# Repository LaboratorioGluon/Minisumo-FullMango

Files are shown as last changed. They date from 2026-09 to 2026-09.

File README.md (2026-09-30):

# 🤖 Robot 🤖 Minisumo FullMango

Mi robot de competición para la OSHWDEM 2026, el minisumo :tangerine: **FullMango** :tangerine:  (Perdón, no había emoji de un mango).

Hecho 100% en directos de Twitch y Youtube, desde las pruebas de concepto, la electrónica con PCB y la programación del microcontrolador de ST.
-   Twitch: [www.twitch.tv/labgluon](https://www.twitch.tv/labgluon)
-   Youtube: [www.youtube.com/labgoratoriogluon](www.youtube.com/labgoratoriogluon)

<p align="center">
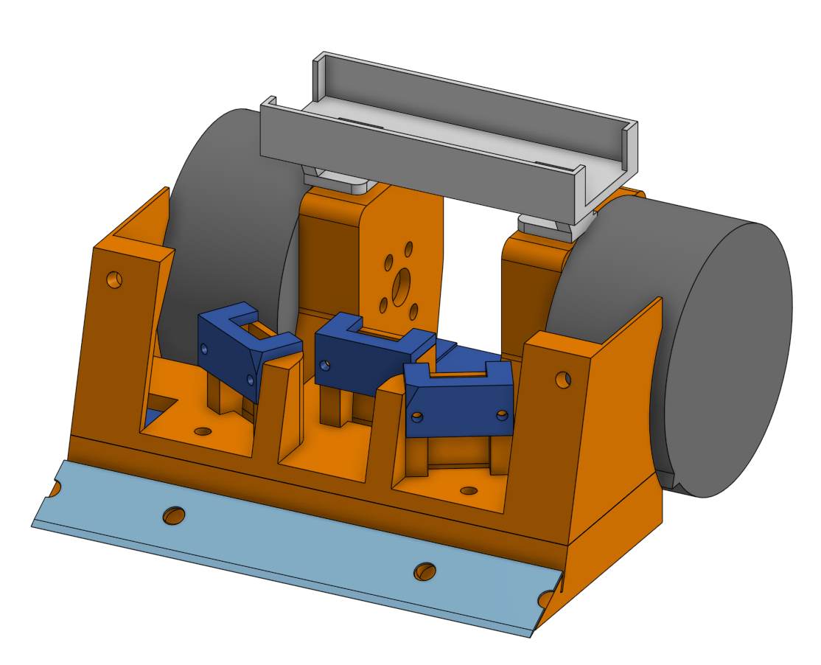
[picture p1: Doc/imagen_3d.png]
Imagen 3D

</p>

# :wrench: Componentes Principales :wrench:
- **PCB** : Diseño propio hecho en KiCAD, proyecto en carpeta `Schematics/MinisumoV2/`
- **Estructura:** Para añadir peso y consistencia esta basado en placas perforadas de acero cincado.
    - Diseño 3D alrededor de estas piezas hecho en OnShape (carpeta `3D').
- **Motores**: De maquina de tatuaje, coreless (Modelo M2610, Ref: [Aliexpress](https://es.aliexpress.com/item/4001010632280.html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))
- **Electrónica**:
    - *Procesador*: **STM32H523CCT6**
    - *Driver motores*: **MP6551**
    - *Sensor de línea*: **QRE1113** (Ref: [Aliexpress](https://s.click.aliexpress.com/e/_c4XDYlMh))
    - *Senor de enemigo*:  **GP2Y0E03** (Ref [Aliexpress](https://s.click.aliexpress.com/e/_c443dXyh))
    - *Alimentación* :
        - Batería 3S Tattu 550 mAh
        - Regulador switching: **TPS563201**
        - Regulador lineal: **AMS1117-3.3**

# :computer: Sobre el Software :computer:

El robot minisumo FullMango se basa en un control por máquina de estados. Siendo los 3 principales:
- **Wait RC5** (`start_state` en el código): Una vez que el Robot se ha inicializado correctamente espera a la señal del **mando RC5**
- **Seek** (`seek_state`): Es el patrón de búsqueda hasta encontrar al enemigo.
- **Attack** (`fight_state`): Cuando el robot ya ha encontrado al enemigo y va a por él.

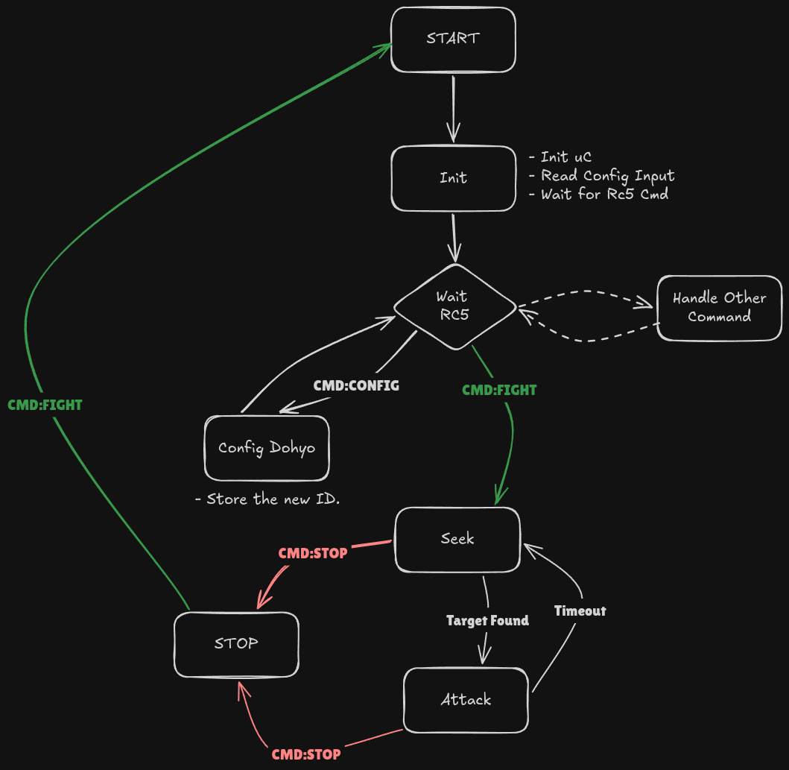
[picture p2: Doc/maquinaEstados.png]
Maquina de Estados de SW.


## Control de motores

Para el control de motores se ha implementado una doble rampa de cara a intentar resolver el problema de los caballitos: los motores son muy potentes y si pasamos al 80% de golpe, el **robot se da la vuelta**.

# Configuracion

| Pin | Function |
| --- | --- |
| Ninguno | FWD |
| 1 | RIGHT |
| 2 | LEFT |
| 3 | BACK |

# Otros enlaces

- [Pagina Web (Castellano)](https://www.laboratoriogluon.com/)
- [Webpage (English)](https://en.laboratoriogluon.com/)

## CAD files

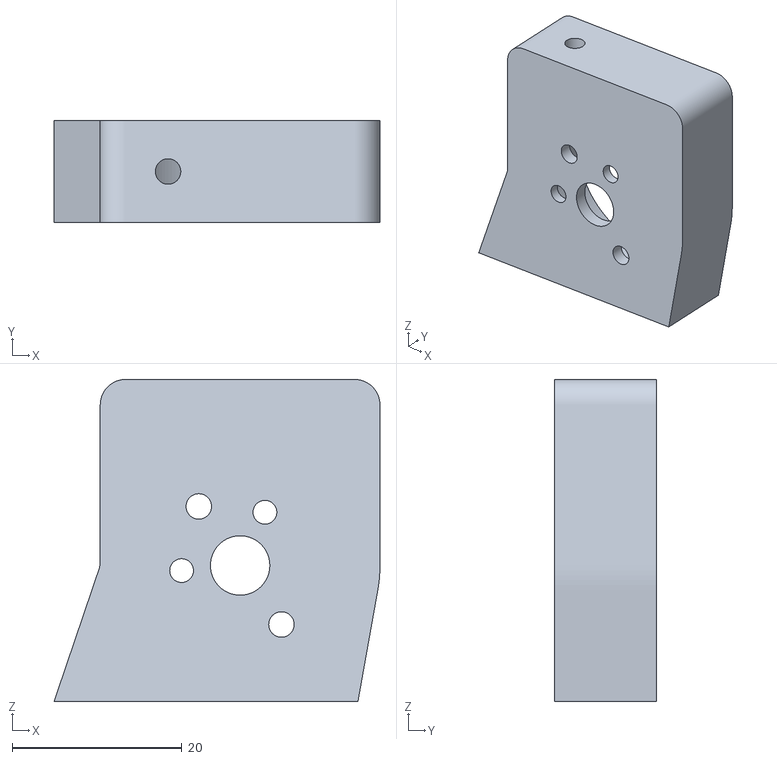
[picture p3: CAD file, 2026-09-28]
3D/FullMango-SoporteDrch.stl
38.5 x 12.0 x 38.0

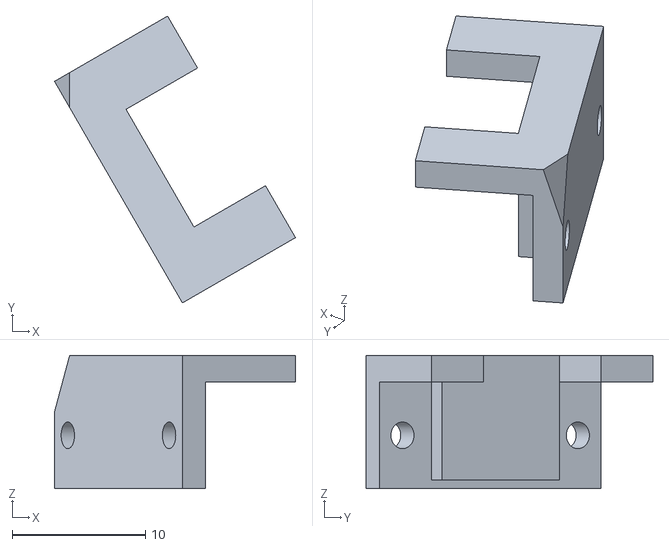
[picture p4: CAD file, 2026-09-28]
3D/FullMango-Part 16.stl
18.1 x 21.5 x 10.00

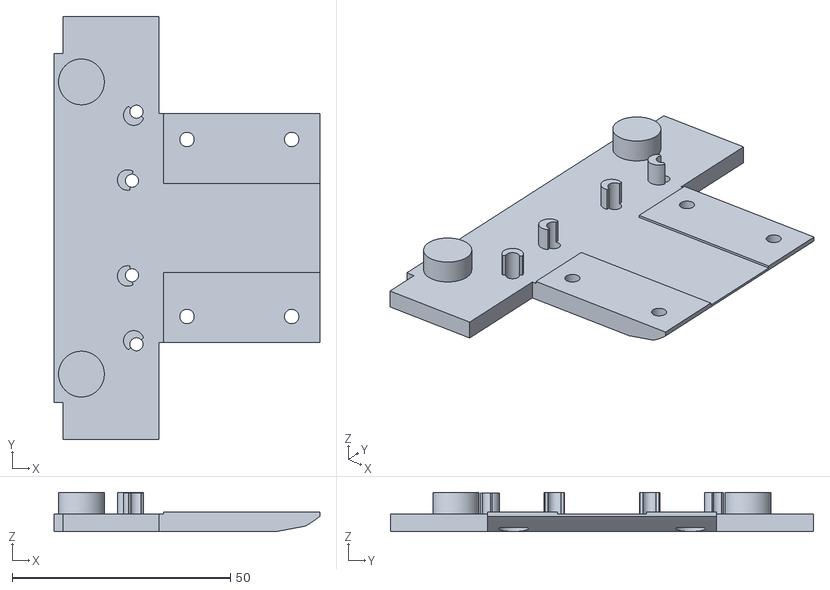
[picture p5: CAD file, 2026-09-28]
3D/FullMango-BaseTRas.stl
60.9 x 97.0 x 9.00

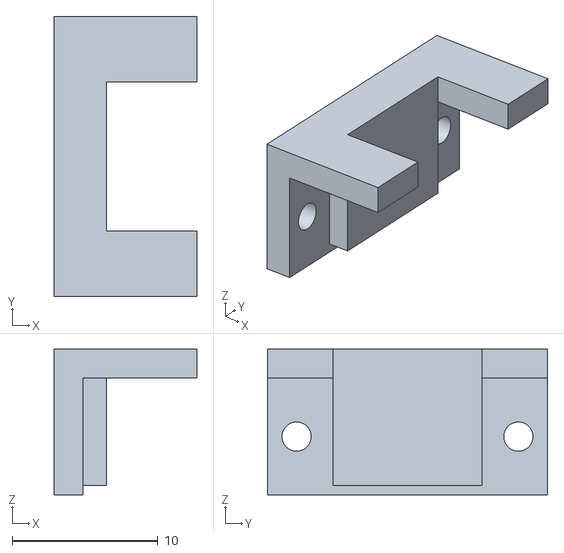
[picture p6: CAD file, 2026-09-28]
3D/FullMango-Part 14.stl
9.80 x 19.2 x 10.00

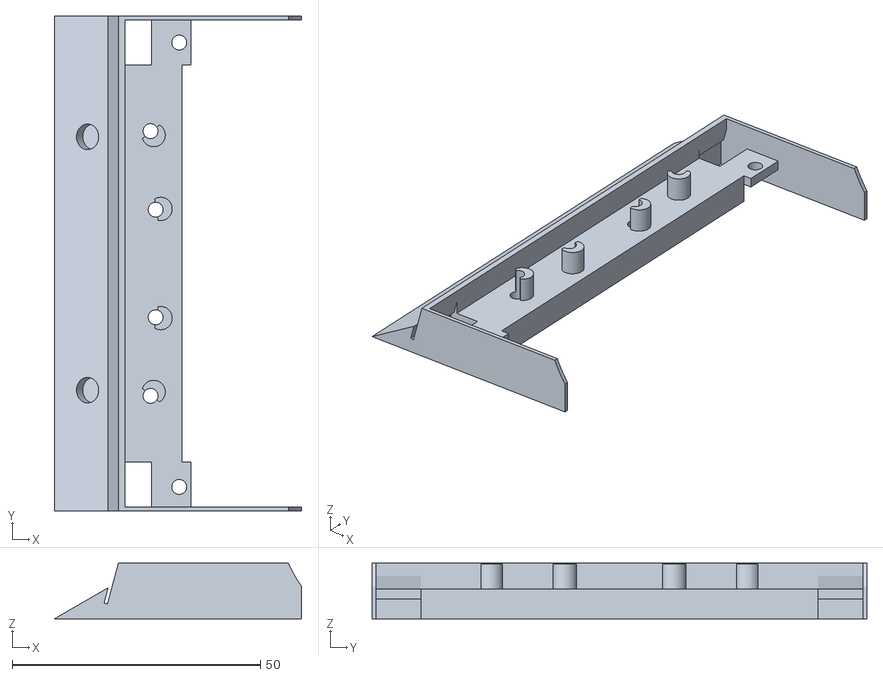
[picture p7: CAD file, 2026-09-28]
3D/FullMango-Frontal_2.stl
49.8 x 99.7 x 11.2

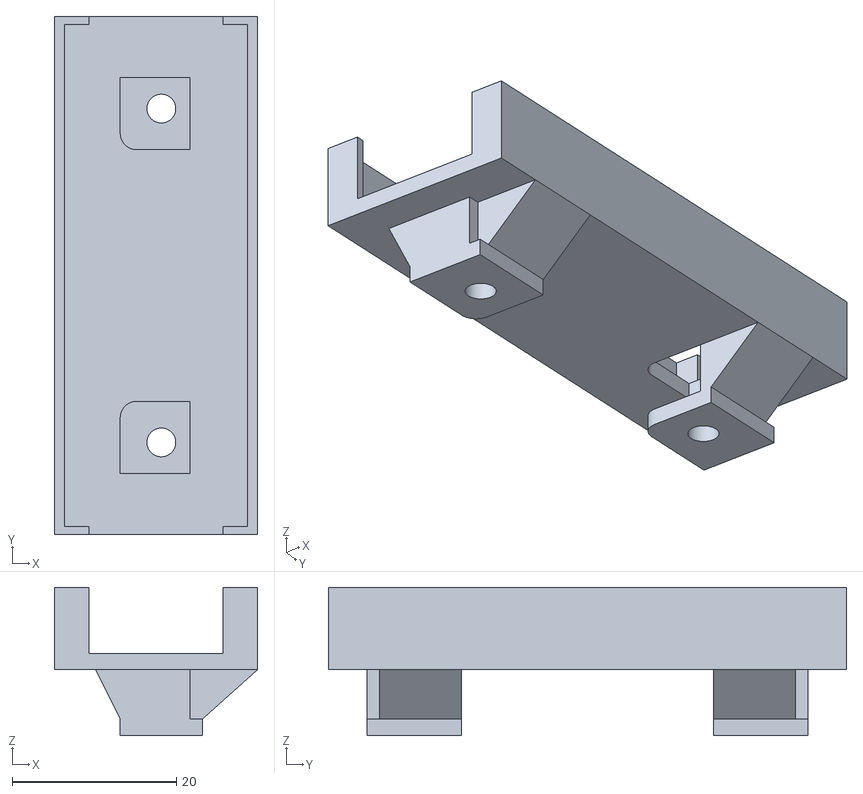
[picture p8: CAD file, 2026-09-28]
3D/FullMango-Part 15.stl
24.7 x 63.0 x 18.0

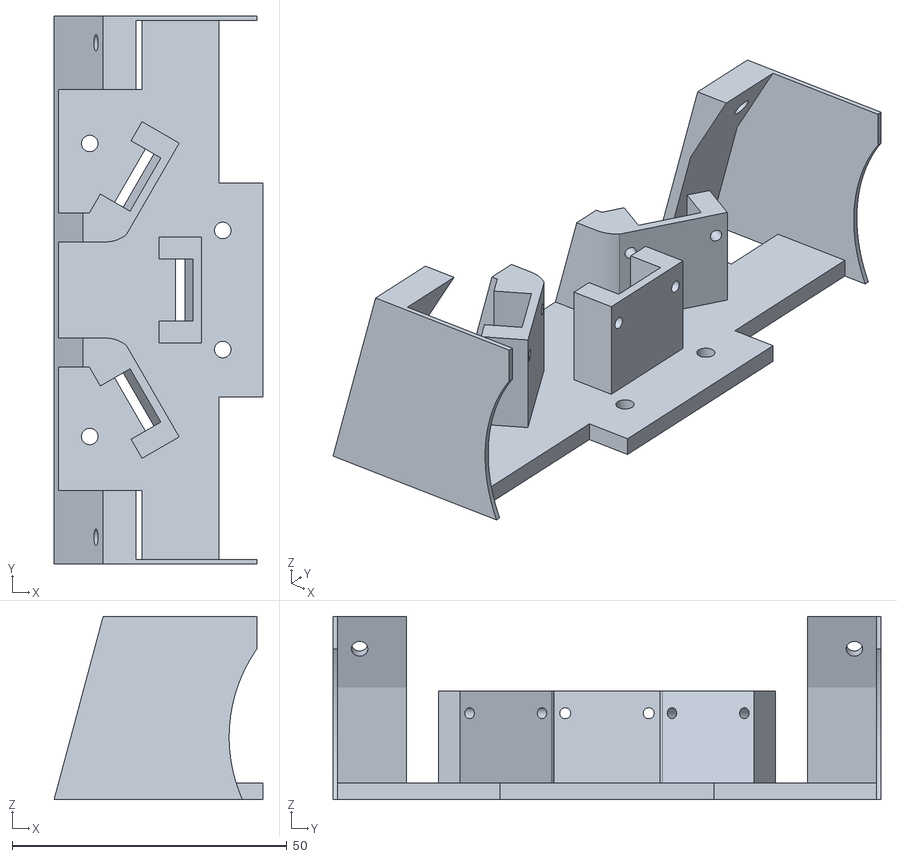
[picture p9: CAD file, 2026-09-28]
3D/FullMango-Frontal.stl
38.0 x 99.7 x 33.3

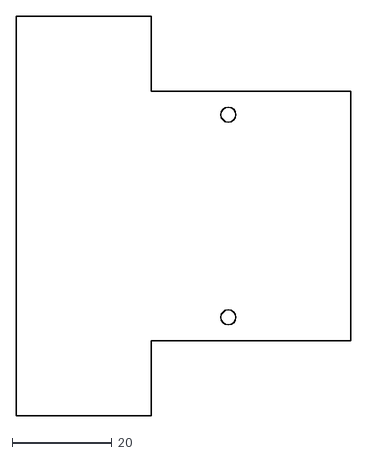
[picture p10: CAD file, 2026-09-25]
Schematics/EdgeCuts_PCB.dxf
67.0 x 80.0

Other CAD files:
3D/FullMango-Part 17.stl
3D/FullMango-SoporteIzda.stl

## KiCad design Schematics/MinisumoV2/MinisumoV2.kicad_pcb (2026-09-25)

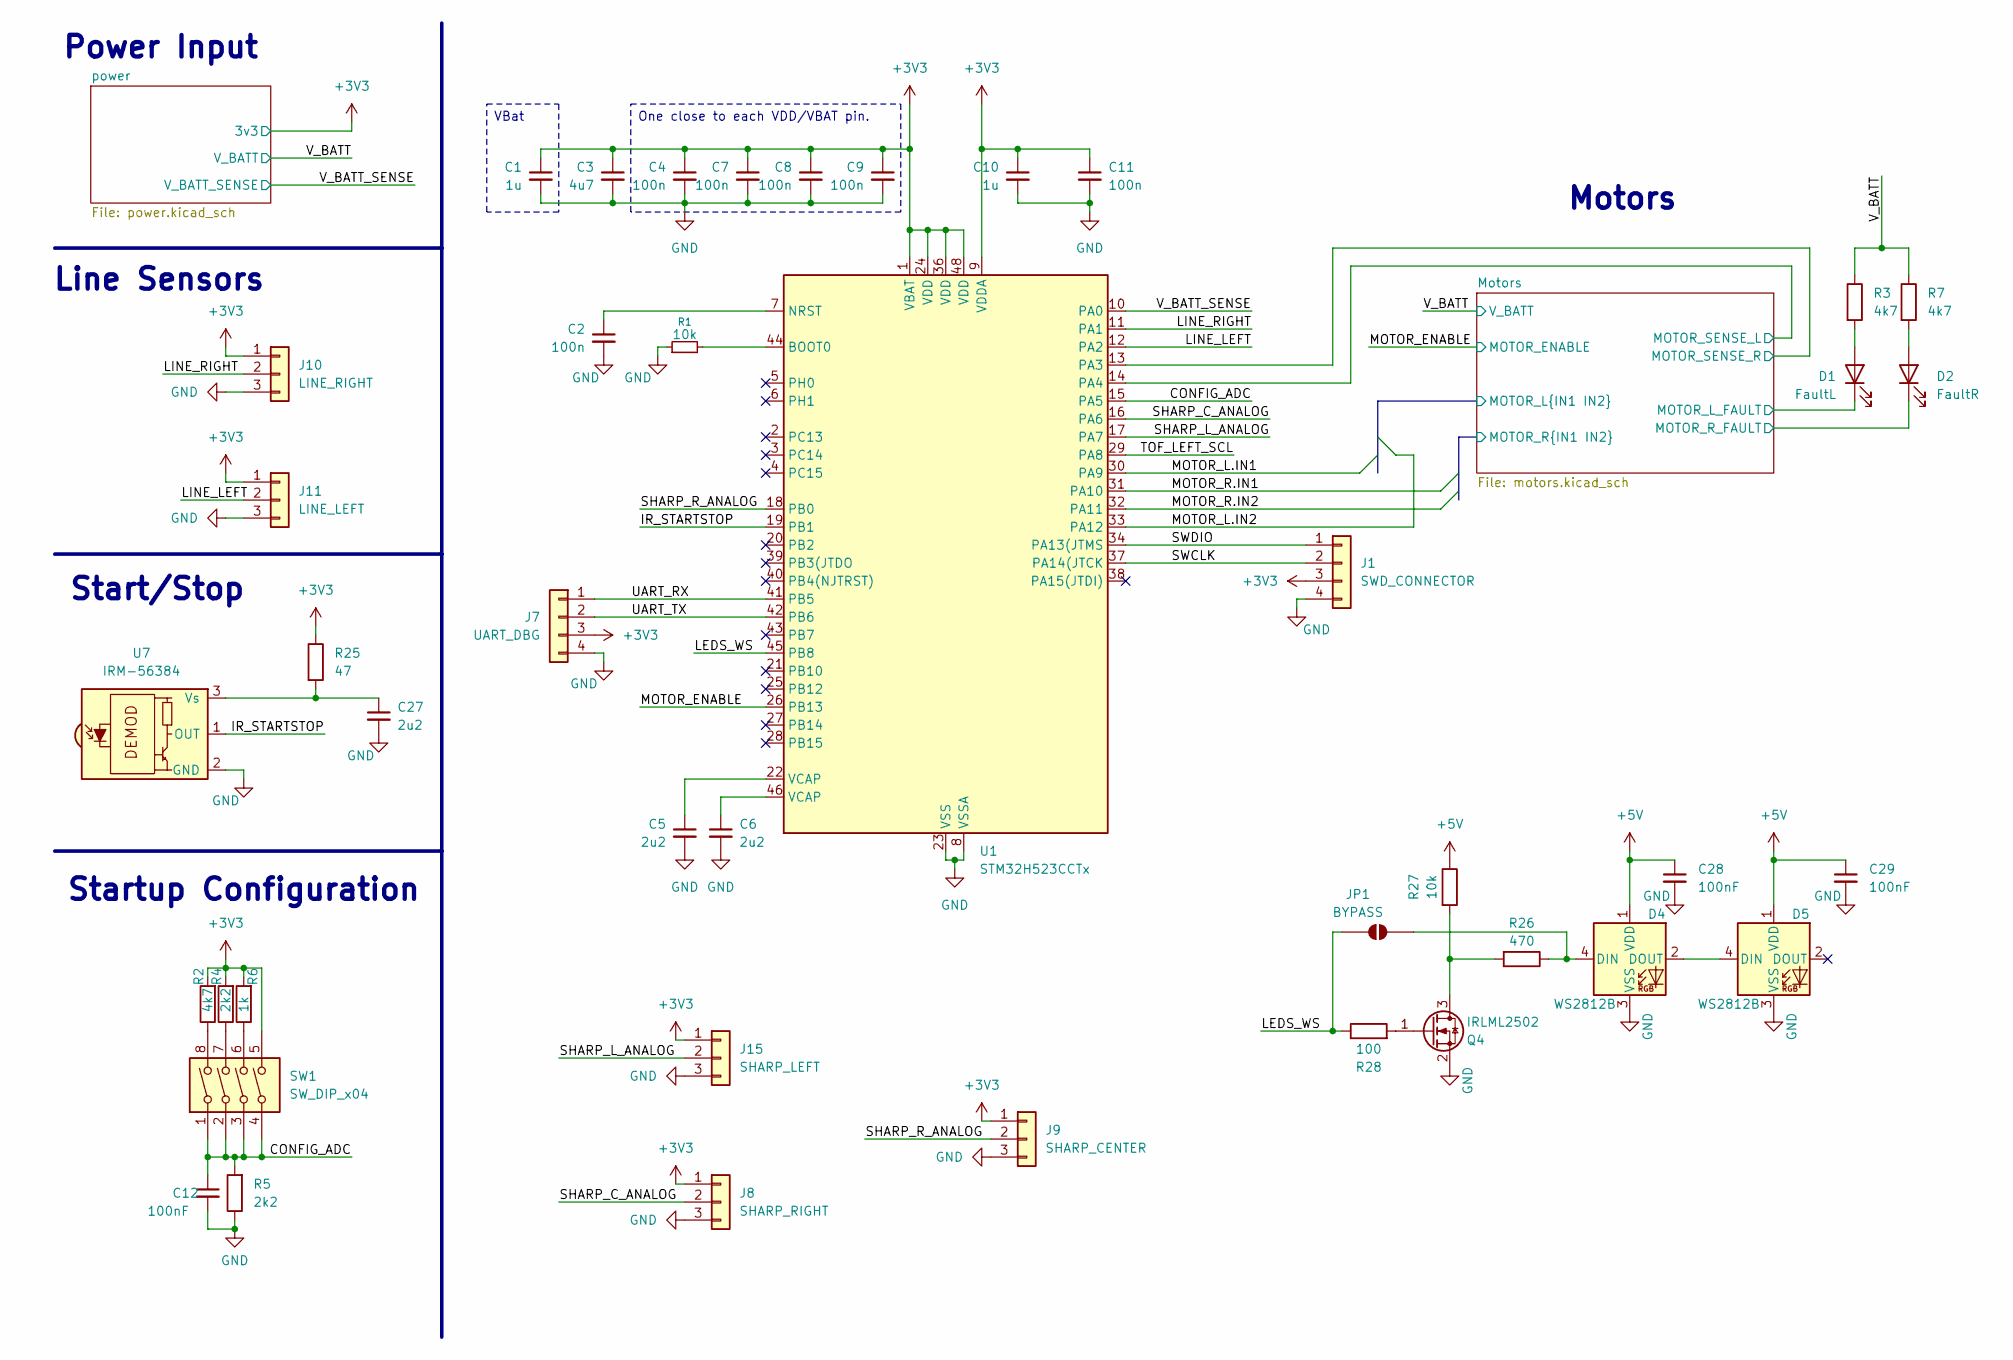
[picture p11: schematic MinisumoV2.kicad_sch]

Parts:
C1, C10: 1u; C_0603_1608Metric_Pad1.08x0.95mm_HandSolder
C2, C4, C7, C8, C9, C11: 100n; C_0603_1608Metric_Pad1.08x0.95mm_HandSolder
C3: 4u7; C_0603_1608Metric_Pad1.08x0.95mm_HandSolder
C5, C6, C27: 2u2; C_0603_1608Metric_Pad1.08x0.95mm_HandSolder
C12, C28, C29: 100nF; C_0805_2012Metric_Pad1.18x1.45mm_HandSolder
D1: FaultL; LED_1206_3216Metric_Pad1.42x1.75mm_HandSolder
D2: FaultR; LED_1206_3216Metric_Pad1.42x1.75mm_HandSolder
D4, D5: WS2812B; LED_WS2812B_PLCC4_5.0x5.0mm_P3.2mm
J1: SWD_CONNECTOR; PinHeader_1x04_P2.54mm_Vertical
J7: UART_DBG; PinHeader_1x04_P2.54mm_Vertical
J8: SHARP_RIGHT; PinHeader_1x03_P2.00mm_Vertical
J9: SHARP_CENTER; PinHeader_1x03_P2.00mm_Vertical
J10: LINE_RIGHT; PinHeader_1x03_P2.00mm_Vertical
J11: LINE_LEFT; PinHeader_1x03_P2.00mm_Vertical
J15: SHARP_LEFT; PinHeader_1x03_P2.00mm_Vertical
JP1: BYPASS; SolderJumper-2_P1.3mm_Open_RoundedPad1.0x1.5mm
Q4: IRLML2502; SOT-23; PartNumber IRLML2502TRPBF
R1: 10k; R_0603_1608Metric_Pad0.98x0.95mm_HandSolder
R2, R3, R7: 4k7; R_0603_1608Metric_Pad0.98x0.95mm_HandSolder
R4, R5: 2k2; R_0603_1608Metric_Pad0.98x0.95mm_HandSolder
R6: 1k; R_0603_1608Metric_Pad0.98x0.95mm_HandSolder
R25: 47; R_0603_1608Metric_Pad0.98x0.95mm_HandSolder
R26: 470; R_0805_2012Metric_Pad1.20x1.40mm_HandSolder
R27: 10k; R_0805_2012Metric_Pad1.20x1.40mm_HandSolder
R28: 100; R_0805_2012Metric_Pad1.20x1.40mm_HandSolder
SW1: SW_DIP_x04; SW_DIP_SPSTx04_Slide_9.78x12.34mm_W8.61mm_P2.54mm
U1: STM32H523CCTx; LQFP-48_7x7mm_P0.5mm
U7: IRM-56384; Vishay_MOLD-3Pin

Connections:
+3V3: C1.1, C3.1, C4.1, C7.1, C8.1, C9.1, C10.1, C11.1, J1.3, J7.3, J8.1, J9.1, J10.1, J11.1, J15.1, R2.2, R4.2, R6.2, R25.1, SW1.5, U1.1 (VBAT), U1.9 (VDDA), U1.24 (VDD), U1.36 (VDD), U1.48 (VDD); also elsewhere on the board
+5V: C28.1, C29.1, D4.1 (VDD), D5.1 (VDD), R27.1; also elsewhere on the board
/CONFIG_ADC: C12.1, R5.2, SW1.1, SW1.2, SW1.3, SW1.4, U1.15 (PA5)
/IR_STARTSTOP: U1.19 (PB1), U7.1 (OUT)
/LEDS_WS: JP1.1 (A), R28.1, U1.45 (PB8)
/LINE_LEFT: J11.2, U1.12 (PA2)
/LINE_RIGHT: J10.2, U1.11 (PA1)
/MOTOR_ENABLE: U1.26 (PB13); also elsewhere on the board
/Motors/MOTOR_L.IN1: U1.30 (PA9); also elsewhere on the board
/Motors/MOTOR_L.IN2: U1.33 (PA12); also elsewhere on the board
/Motors/MOTOR_L_FAULT: D1.1 (K); also elsewhere on the board
/Motors/MOTOR_R.IN1: U1.31 (PA10); also elsewhere on the board
/Motors/MOTOR_R.IN2: U1.32 (PA11); also elsewhere on the board
/Motors/MOTOR_R_FAULT: D2.1 (K); also elsewhere on the board
/Motors/MOTOR_SENSE_L: U1.14 (PA4); also elsewhere on the board
/Motors/MOTOR_SENSE_R: U1.13 (PA3); also elsewhere on the board
/SHARP_C_ANALOG: J8.2, U1.16 (PA6)
/SHARP_L_ANALOG: J15.2, U1.17 (PA7)
/SHARP_R_ANALOG: J9.2, U1.18 (PB0)
/SWCLK: J1.2, U1.37 (PA14(JTCK)
/SWDIO: J1.1, U1.34 (PA13(JTMS)
/TOF_LEFT_SCL: U1.29 (PA8)
/UART_RX: J7.1, U1.41 (PB5)
/UART_TX: J7.2, U1.42 (PB6)
/V_BATT: R3.1, R7.1; also elsewhere on the board
/V_BATT_SENSE: U1.10 (PA0); also elsewhere on the board
GND: C1.2, C2.2, C3.2, C4.2, C5.2, C6.2, C7.2, C8.2, C9.2, C10.2, C11.2, C12.2, C27.2, C28.2, C29.2, D4.3 (VSS), D5.3 (VSS), J1.4, J7.4, J8.3, J9.3, J10.3, J11.3, J15.3, Q4.2 (S), R1.1, R5.1, U1.8 (VSSA), U1.23 (VSS), U1.35 (VSS), U1.47 (VSS), U7.2 (GND); also elsewhere on the board
unnamed: C5.1, U1.22 (VCAP)
unnamed: C6.1, U1.46 (VCAP)
unnamed: D1.2 (A), R3.2
unnamed: D2.2 (A), R7.2
unnamed: D4.4 (DIN), JP1.2 (B), R26.1
unnamed: D4.2 (DOUT), D5.4 (DIN)
unnamed: Q4.3 (D), R26.2, R27.2
unnamed: Q4.1 (G), R28.2
unnamed: R2.1, SW1.8
unnamed: R4.1, SW1.7
unnamed: R6.1, SW1.6
unnamed: R1.2, U1.44 (BOOT0)
unnamed: C2.1, U1.7 (NRST)
unnamed: C27.1, R25.2, U7.3 (Vs)

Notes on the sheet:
Line Sensors
Power Input
Start/Stop
Motors
Startup Configuration
VBat
One close to each VDD/VBAT pin.

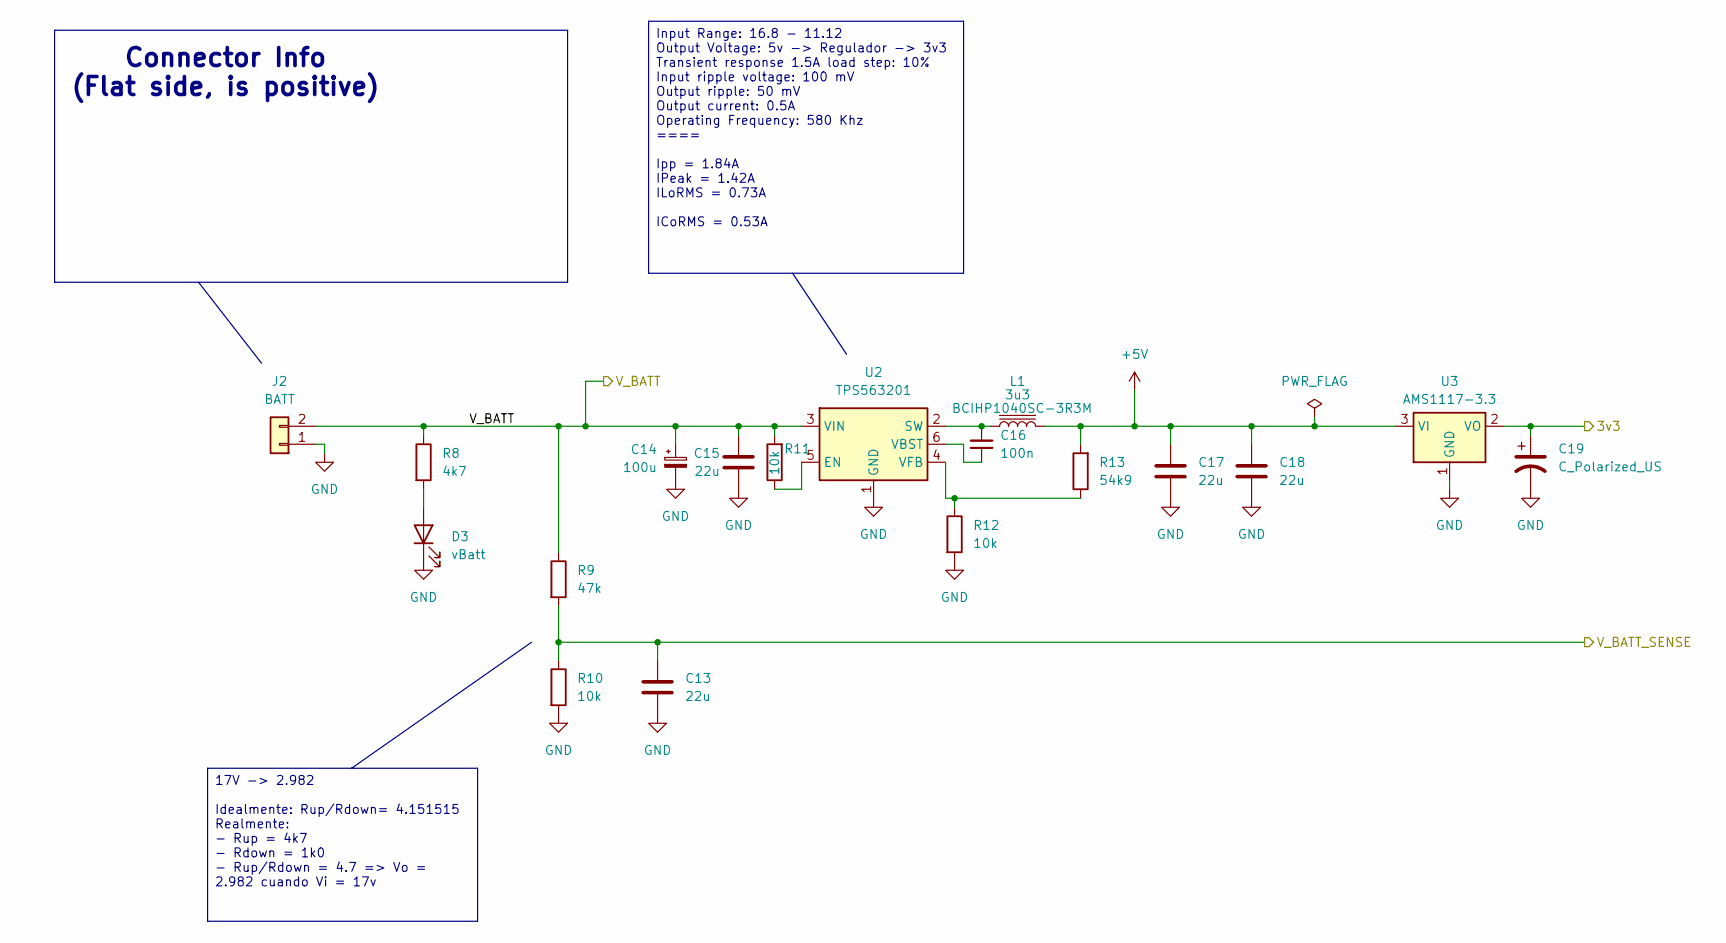
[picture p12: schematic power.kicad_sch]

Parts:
C13: 22u; C_0603_1608Metric_Pad1.08x0.95mm_HandSolder
C14: 100u; CP_Elec_6.3x5.4
C15, C17, C18: 22u; C_0805_2012Metric_Pad1.18x1.45mm_HandSolder
C16: 100n; C_0805_2012Metric_Pad1.18x1.45mm_HandSolder
C19: C_Polarized_US; CP_Elec_4x5.3
D3: vBatt; LED_1206_3216Metric_Pad1.42x1.75mm_HandSolder
J2: BATT; AMASS_XT30PW-M_1x02_P2.50mm_Horizontal
L1: 3u3; L_Sunlord_MWSA0412S
R8: 4k7; R_0603_1608Metric_Pad0.98x0.95mm_HandSolder
R9: 47k; R_0603_1608Metric_Pad0.98x0.95mm_HandSolder
R10, R11, R12: 10k; R_0603_1608Metric_Pad0.98x0.95mm_HandSolder
R13: 54k9; R_0603_1608Metric_Pad0.98x0.95mm_HandSolder
U2: TPS563201; SOT-23-6
U3: AMS1117-3.3; SOT-223-3_TabPin2

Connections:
+3V3: C19.1, U3.2 (VO); also elsewhere on the board
+5V: C17.1, C18.1, L1.2, R13.2, U3.3 (VI); also elsewhere on the board
/V_BATT: C14.1, C15.1, J2.2, R8.1, R9.1, R11.2, U2.3 (VIN); also elsewhere on the board
/V_BATT_SENSE: C13.1, R9.2, R10.1; also elsewhere on the board
GND: C13.2, C14.2, C15.2, C17.2, C18.2, C19.2, D3.1 (K), J2.1, R10.2, R12.2, U2.1 (GND), U3.1 (GND); also elsewhere on the board
unnamed: D3.2 (A), R8.2
unnamed: R11.1, U2.5 (EN)
unnamed: C16.2, L1.1, U2.2 (SW)
unnamed: C16.1, U2.6 (VBST)
unnamed: R12.1, R13.1, U2.4 (VFB)

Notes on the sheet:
Connector Info (Flat side, is positive)
Input Range: 16.8 - 11.12 Output Voltage: 5v -> Regulador -> 3v3 Transient response 1.5A load step: 10% Input ripple voltage: 100 mV Output ripple: 50 mV Output current: 0.5A Operating Frequency: 580 Khz ==== Ipp = 1.84A IPeak = 1.42A ILoRMS = 0.73A ICoRMS = 0.53A
17V -> 2.982 Idealmente: Rup/Rdown= 4.151515 Realmente: - Rup = 4k7 - Rdown = 1k0 - Rup/Rdown = 4.7 => Vo = 2.982 cuando Vi = 17v

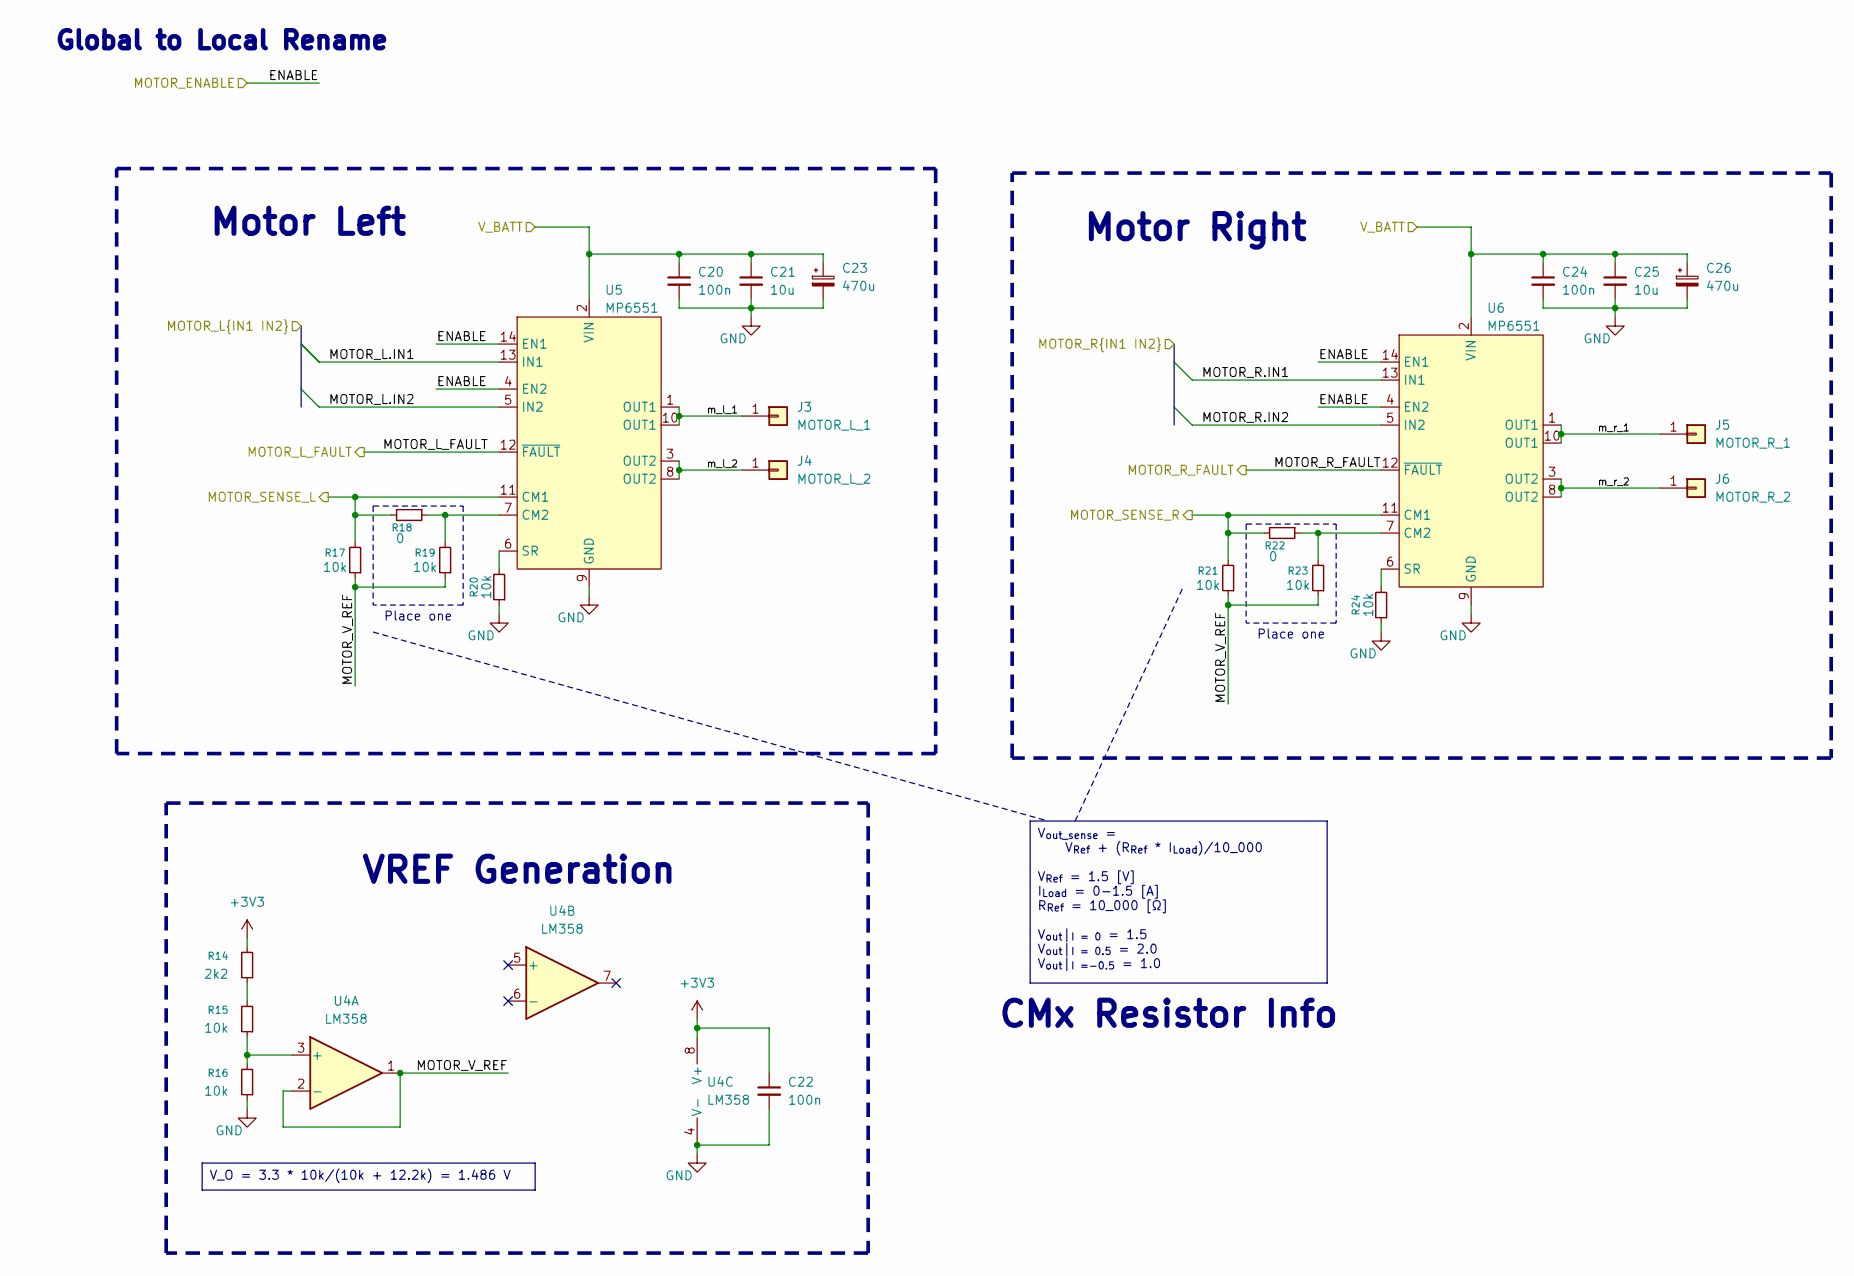
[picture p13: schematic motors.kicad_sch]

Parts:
C20, C22, C24: 100n; C_0603_1608Metric_Pad1.08x0.95mm_HandSolder
C21, C25: 10u; C_0603_1608Metric_Pad1.08x0.95mm_HandSolder
C23, C26: 470u; CP_Elec_6.3x5.4
J3: MOTOR_L_1; TestPoint_Pad_4.0x4.0mm
J4: MOTOR_L_2; TestPoint_Pad_4.0x4.0mm
J5: MOTOR_R_1; TestPoint_Pad_4.0x4.0mm
J6: MOTOR_R_2; TestPoint_Pad_4.0x4.0mm
R14: 2k2; R_0603_1608Metric_Pad0.98x0.95mm_HandSolder
R15, R16, R17, R19, R20, R21, R23, R24: 10k; R_0603_1608Metric_Pad0.98x0.95mm_HandSolder
R18, R22: 0; R_0603_1608Metric_Pad0.98x0.95mm_HandSolder
U4: LM358; SOIC-8_3.9x4.9mm_P1.27mm
U5, U6: MP6551; QFN-14_MP6551_MNP

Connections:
+3V3: C22.1, R14.2, U4.8 (V+); also elsewhere on the board
/MOTOR_ENABLE: U5.4 (EN2), U5.14 (EN1), U6.4 (EN2), U6.14 (EN1); also elsewhere on the board
/Motors/MOTOR_L.IN1: U5.13 (IN1); also elsewhere on the board
/Motors/MOTOR_L.IN2: U5.5 (IN2); also elsewhere on the board
/Motors/MOTOR_L_FAULT: U5.12 (~FAULT); also elsewhere on the board
/Motors/MOTOR_R.IN1: U6.13 (IN1); also elsewhere on the board
/Motors/MOTOR_R.IN2: U6.5 (IN2); also elsewhere on the board
/Motors/MOTOR_R_FAULT: U6.12 (~FAULT); also elsewhere on the board
/Motors/MOTOR_SENSE_L: R17.2, R18.2, U5.11 (CM1); also elsewhere on the board
/Motors/MOTOR_SENSE_R: R21.2, R22.2, U6.11 (CM1); also elsewhere on the board
/Motors/MOTOR_V_REF: R17.1, R19.1, R21.1, R23.1, U4.1, U4.2 (-)
/Motors/m_l_1: J3.1 (Pin_1_1), U5.1 (OUT1), U5.10 (OUT1)
/Motors/m_l_2: J4.1 (Pin_1_1), U5.3 (OUT2), U5.8 (OUT2)
/Motors/m_r_1: J5.1 (Pin_1_1), U6.1 (OUT1), U6.10 (OUT1)
/Motors/m_r_2: J6.1 (Pin_1_1), U6.3 (OUT2), U6.8 (OUT2)
/V_BATT: C20.1, C21.1, C23.1, C24.1, C25.1, C26.1, U5.2 (VIN), U6.2 (VIN); also elsewhere on the board
GND: C20.2, C21.2, C22.2, C23.2, C24.2, C25.2, C26.2, R16.1, R20.1, R24.1, U4.4 (V-), U5.9 (GND), U6.9 (GND); also elsewhere on the board
unnamed: R14.1, R15.2
unnamed: R15.1, R16.2, U4.3 (+)
unnamed: R18.1, R19.2, U5.7 (CM2)
unnamed: R20.2, U5.6 (SR)
unnamed: R22.1, R23.2, U6.7 (CM2)
unnamed: R24.2, U6.6 (SR)

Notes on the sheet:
Global to Local Rename
Place one
VREF Generation
Motor Right
CMx Resistor Info
Motor Left
V_O = 3.3 * 10k/(10k + 12.2k) = 1.486 V
V_{out_sense} = V_{Ref} + (R_{Ref} * I_{Load})/10_000 V_{Ref} = 1.5 [V] I_{Load} = 0-1.5 [A] R_{Ref} = 10_000 [Ω] V_{out}|_{I = 0} = 1.5 V_{out}|_{I = 0.5} = 2.0 V_{out}|_{I =-0.5} = 1.0

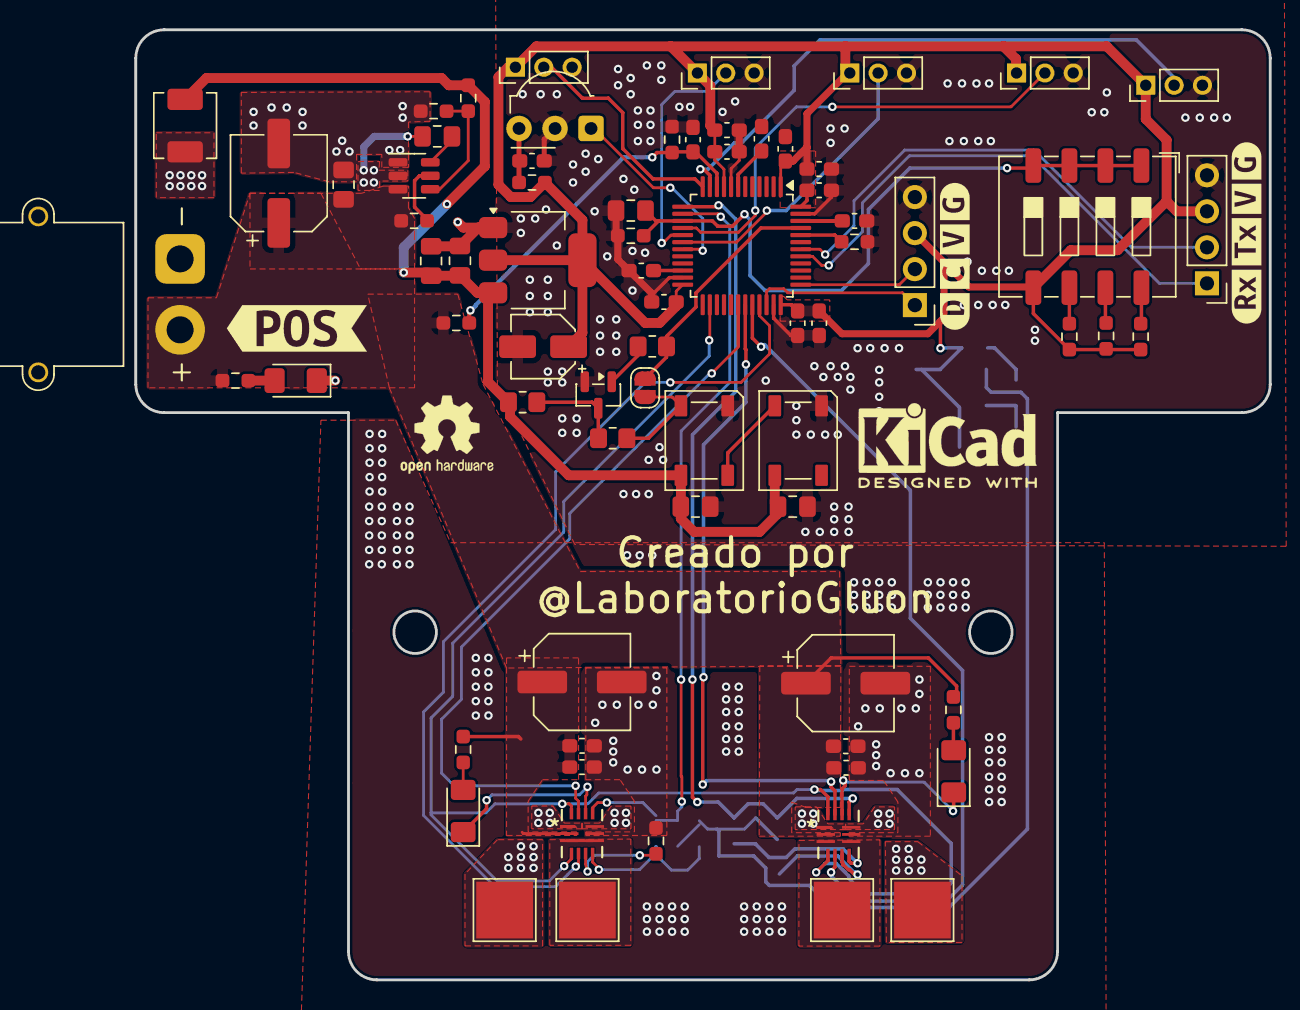
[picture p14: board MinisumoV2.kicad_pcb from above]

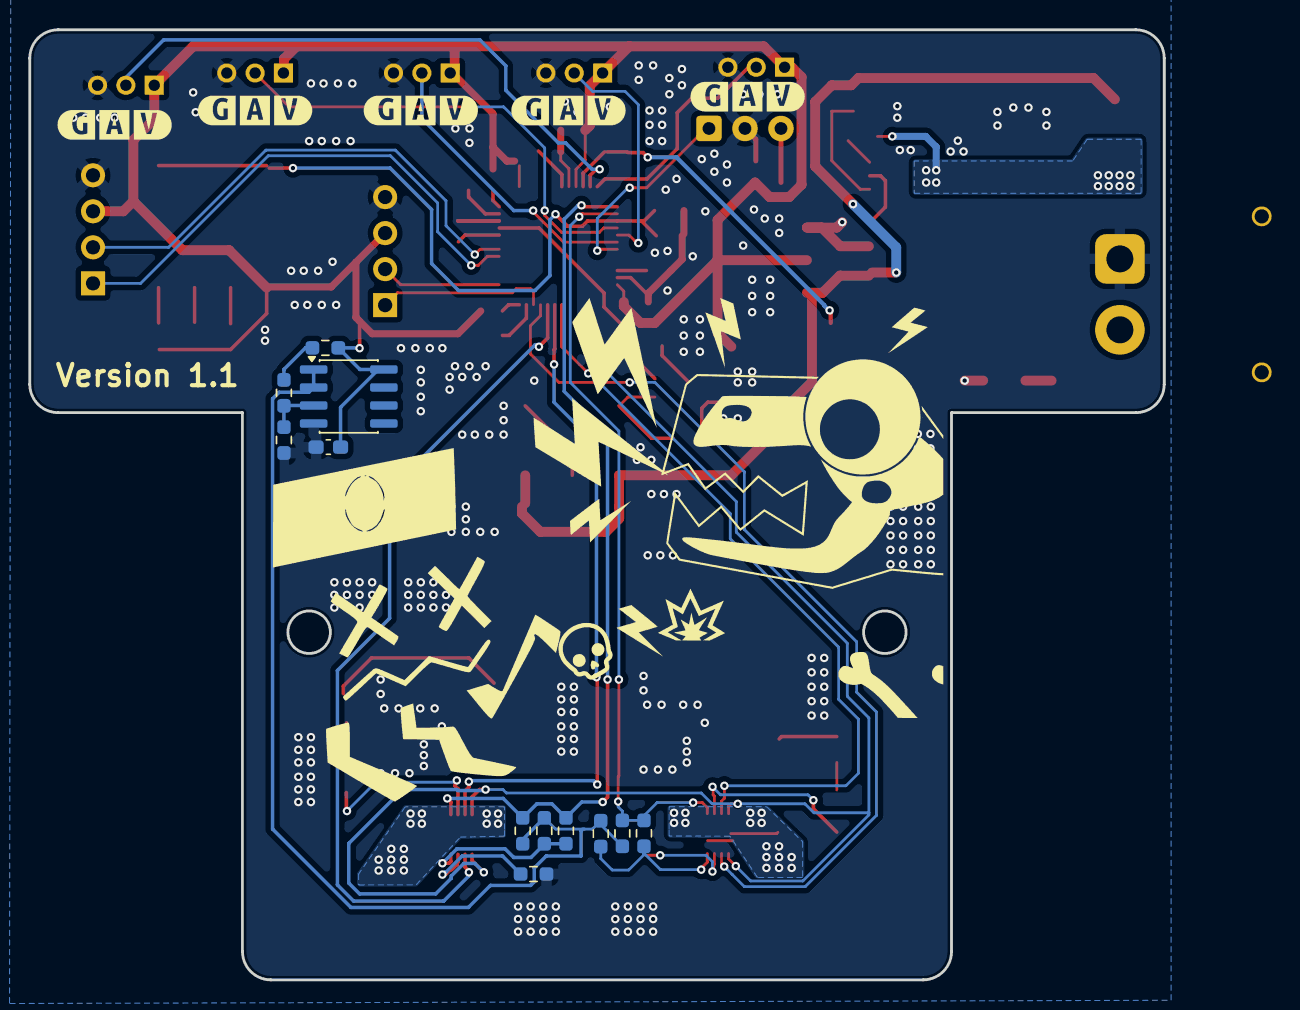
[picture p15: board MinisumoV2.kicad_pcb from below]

Board: 2 copper layers, 80.0 x 67.0 mm, 93 parts (17 on the bottom side), 56 nets.

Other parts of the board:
kibuzzard-6A21495C: G***; kibuzzard-6A21495C
kibuzzard-69A73CC0: G***; kibuzzard-69A73CC0
kibuzzard-69A732F2: G***; kibuzzard-69A732F2
kibuzzard-69A73765: G***; kibuzzard-69A73765
kibuzzard-69A73775, kibuzzard-69A73775#2, kibuzzard-69A73775#3, kibuzzard-69A73775#4: G***; kibuzzard-69A73775

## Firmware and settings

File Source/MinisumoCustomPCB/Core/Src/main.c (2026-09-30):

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
/* Includes ------------------------------------------------------------------*/
#include "main.h"

/* USER CODE BEGIN Includes */
#include <stdint.h>
#include <stdio.h>
#include <string.h>
#include "ee.h"
#include "minisumo.h"
#include "motor.h"
#include "sensors.h"
#include "status.h"
#include "stm32h523xx.h"
#include "stm32h5xx_hal.h"
#include "stm32h5xx_hal_adc.h"
#include "stm32h5xx_hal_adc_ex.h"
#include "stm32h5xx_hal_def.h"
#include "stm32h5xx_hal_gpio.h"
#include "stm32h5xx_hal_tim.h"
#include "stm32h5xx_hal_uart.h"
#include "wsLed.h"

/* USER CODE END Includes */

ADC_HandleTypeDef hadc1;
DMA_HandleTypeDef handle_GPDMA1_Channel1;

TIM_HandleTypeDef htim1;
TIM_HandleTypeDef htim4;
TIM_HandleTypeDef htim6;
TIM_HandleTypeDef htim12;
DMA_HandleTypeDef handle_GPDMA1_Channel0;

UART_HandleTypeDef huart5;

/* USER CODE BEGIN PV */
uint32_t adcConversionCompleted = 0;
/* USER CODE END PV */

void        SystemClock_Config(void);
static void MPU_Config(void);
static void MX_GPIO_Init(void);
static void MX_GPDMA1_Init(void);
static void MX_ICACHE_Init(void);
static void MX_TIM4_Init(void);
static void MX_ADC1_Init(void);
static void MX_UART5_Init(void);
static void MX_TIM1_Init(void);
static void MX_TIM12_Init(void);
static void MX_TIM6_Init(void);
static void MX_FLASH_Init(void);
/**
  * @brief  The application entry point.
  * @retval int
  */
int main(void)
{

    /* MCU Configuration--------------------------------------------------------*/

    /* MPU Configuration--------------------------------------------------------*/

    MPU_Config();

    /* Reset of all peripherals, Initializes the Flash interface and the Systick. */
    HAL_Init();

    /* Configure the system clock */
    SystemClock_Config();

    /* Initialize all configured peripherals */
    MX_GPIO_Init();
    MX_GPDMA1_Init();
    MX_ICACHE_Init();
    MX_TIM4_Init();
    MX_ADC1_Init();
    MX_UART5_Init();
    MX_TIM1_Init();
    MX_TIM12_Init();
    MX_TIM6_Init();
    MX_FLASH_Init();
    /* USER CODE BEGIN 2 */

    HAL_UART_Transmit(&huart5, "Hola soy Minisumo!\r\n", 20, 1000);

    MinisumoConfig config;

    config.statusConfig.dma        = &handle_GPDMA1_Channel0;
    config.statusConfig.tim        = &htim4;
    config.statusConfig.timChannel = TIM_CHANNEL_3;

    config.adc = &hadc1;

    config.rc5Timer = &htim12;

    config.motorLeft.timer          = &htim1;
    config.motorLeft.timerChannel   = TIM_CHANNEL_2;
    config.motorLeft.directionPort  = GPIOA;
    config.motorLeft.directionPin   = GPIO_PIN_12;
    config.motorLeft.isReversed     = 0;
    config.motorRight.timer         = &htim1;
    config.motorRight.timerChannel  = TIM_CHANNEL_3;
    config.motorRight.directionPort = GPIOA;
    config.motorRight.directionPin  = GPIO_PIN_11;
    config.motorRight.isReversed    = 1;
    minisumo_setup(&config);

    HAL_GPIO_WritePin(MOTOR_ENABLE_GPIO_Port, MOTOR_ENABLE_Pin, GPIO_PIN_SET);

    HAL_TIM_Base_Start(&htim6);

    /* USER CODE END 2 */

    /* Infinite loop */
    /* USER CODE BEGIN WHILE */

    HAL_TIM_PWM_Start(config.motorLeft.timer, config.motorLeft.timerChannel);
    HAL_TIM_PWM_Start(config.motorLeft.timer, config.motorRight.timerChannel);
    sensors_init(&hadc1);
    status_rawLeds((Rgb){0, 20, 0}, (Rgb){0, 0, 0});

    while (1) {
        //HAL_UART_Transmit(&huart5, "Hola soy Minisumo!\n", 20, 1000);

        minisumo_loop_new();
        /* USER CODE END WHILE */

        /* USER CODE BEGIN 3 */
    }
    /* USER CODE END 3 */
}

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
/* MPU Configuration */

void MPU_Config(void)
{
    MPU_Region_InitTypeDef     MPU_InitStruct     = {0};
    MPU_Attributes_InitTypeDef MPU_AttributesInit = {0};

    /* Disables the MPU */
    HAL_MPU_Disable();

    /** Initializes and configures the Region 0 and the memory to be protected
  */
    MPU_InitStruct.Enable           = MPU_REGION_ENABLE;
    MPU_InitStruct.Number           = MPU_REGION_NUMBER0;
    MPU_InitStruct.BaseAddress      = 0x08FFF000;
    MPU_InitStruct.LimitAddress     = 0x08FFFFFF;
    MPU_InitStruct.AttributesIndex  = MPU_ATTRIBUTES_NUMBER0;
    MPU_InitStruct.AccessPermission = MPU_REGION_ALL_RO;
    MPU_InitStruct.DisableExec      = MPU_INSTRUCTION_ACCESS_DISABLE;
    MPU_InitStruct.IsShareable      = MPU_ACCESS_NOT_SHAREABLE;

    HAL_MPU_ConfigRegion(&MPU_InitStruct);

    /** Initializes and configures the Region 1 and the memory to be protected
  */
    MPU_InitStruct.Number           = MPU_REGION_NUMBER1;
    MPU_InitStruct.BaseAddress      = 0x0900C000;
    MPU_InitStruct.LimitAddress     = 0x09017FFF;
    MPU_InitStruct.AccessPermission = MPU_REGION_ALL_RW;

    HAL_MPU_ConfigRegion(&MPU_InitStruct);

    /** Initializes and configures the Attribute 0 and the memory to be protected
  */
    MPU_AttributesInit.Number     = MPU_ATTRIBUTES_NUMBER0;
    MPU_AttributesInit.Attributes = INNER_OUTER(MPU_NOT_CACHEABLE);

    HAL_MPU_ConfigMemoryAttributes(&MPU_AttributesInit);
    /* Enables the MPU */
    HAL_MPU_Enable(MPU_PRIVILEGED_DEFAULT);
}

/**
  * @brief  This function is executed in case of error occurrence.
  * @retval None
  */
void Error_Handler(void)
{
    /* USER CODE BEGIN Error_Handler_Debug */
    /* User can add his own implementation to report the HAL error return state */
    __disable_irq();
    while (1) {}
    /* USER CODE END Error_Handler_Debug */
}
#ifdef USE_FULL_ASSERT
/**
  * @brief  Reports the name of the source file and the source line number
  *         where the assert_param error has occurred.
  * @param  file: pointer to the source file name
  * @param  line: assert_param error line source number
  * @retval None
  */
void assert_failed(uint8_t* file, uint32_t line)
{
    /* USER CODE BEGIN 6 */
    /* User can add his own implementation to report the file name and line
     number, ex: printf("Wrong parameters value: file %s on line %d\r\n", file,
     line) */
    /* USER CODE END 6 */
}
#endif /* USE_FULL_ASSERT */

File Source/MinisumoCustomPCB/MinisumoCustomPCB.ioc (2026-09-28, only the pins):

Mcu.UserName=STM32H523CCTx
PA0.GPIO_Label=V_BATT_SENSE
PA0.Signal=ADCx_INP0
PA1.GPIO_Label=LINE_RIGHT
PA1.Signal=ADCx_INP1
PA10.Signal=S_TIM1_CH3
PA11.Signal=GPIO_Output
PA12.Signal=GPIO_Output
PA2.GPIO_Label=LINE_LEFT
PA2.Signal=ADCx_INP14
PA3.GPIO_Label=MOTOR_SENSE_R
PA3.Signal=ADCx_INP15
PA4.GPIO_Label=MOTOR_SENSE_L
PA4.Signal=ADCx_INP18
PA5.GPIO_Label=CONFIG_ADC
PA5.Signal=ADCx_INP19
PA6.GPIO_Label=SHARP_C_ANALOG
PA6.Signal=ADCx_INP3
PA7.GPIO_Label=SHARP_L_ANALOG
PA7.Signal=ADCx_INP7
PA9.Signal=S_TIM1_CH2
PB0.GPIO_Label=SHARP_R_ANALOG
PB0.Signal=ADCx_INP9
PB1.Signal=GPXTI1
PB13.GPIO_Label=MOTOR_ENABLE
PB13.Signal=GPIO_Output
PB5.Signal=UART5_RX
PB6.Signal=UART5_TX
PB8.Signal=S_TIM4_CH3

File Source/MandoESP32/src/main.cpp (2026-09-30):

#include <freertos/FreeRTOS.h>
#include "rc5.h"
#include <ssd1306.h>
#include <esp_log.h>
#include "menu.h"
#include <string.h>
// #include "common.h"

constexpr uint8_t ADDR_STARTSTOP = 0x07;
constexpr uint8_t ADDR_PROGRAMMING = 0x0B;

constexpr gpio_num_t BUTTON_LEFT = GPIO_NUM_5;
constexpr gpio_num_t BUTTON_CENTER = GPIO_NUM_6;
constexpr gpio_num_t BUTTON_RIGHT = GPIO_NUM_7;
constexpr gpio_num_t OLED_SDA = GPIO_NUM_8;
constexpr gpio_num_t OLED_SCL = GPIO_NUM_9;

constexpr gpio_num_t SLIDER_UP = GPIO_NUM_21;
constexpr gpio_num_t SLIDER_DOWN = GPIO_NUM_10;
constexpr gpio_num_t SLIDER_PRESS = GPIO_NUM_20;

// OLED
ssd1306_config_t dev_cfg = I2C_SSD1306_128x64_CONFIG_DEFAULT;
ssd1306_handle_t dev_hdl;

// I2C
i2c_master_bus_handle_t busHandle;
i2c_master_dev_handle_t devHandle;

uint8_t selectedMenuIndex = 0;

uint8_t menuOptions[8][50] =
    {
        "Enemy Front",
        "Enemy Left",
        "Enemy Right",
        "",
        "",
        "",
        "",
        "",
};

void update_screen()
{
    /*ssd1306_clear_display(dev_hdl, false);
    ssd1306_set_contrast(dev_hdl, 0xff);
    ssd1306_clear_display(dev_hdl, false);*/
    for (uint8_t i = 0; i < 8; i++)
    {
        if (strlen((char *)menuOptions[i]) > 0)
        {
            ssd1306_display_text(dev_hdl, i, (char *)menuOptions[i], selectedMenuIndex == i);
        }
        /*ssd1306_display_text(dev_hdl, 0, "SSD1306 128x64", false);
        ssd1306_display_text(dev_hdl, 1, "Hello World!!", false);
        ssd1306_display_text(dev_hdl, 2, "SSD1306 128x64", true);
        ssd1306_display_text(dev_hdl, 3, "Hello World!!", true);*/
    }
}

static void i2c_scanner_task()
{
    esp_log_level_set("i2c.master", ESP_LOG_NONE);
    // Configure and initialize the I2C master bus
    i2c_master_bus_config_t bus_cfg = {
        .i2c_port = I2C_NUM_0,
        .sda_io_num = OLED_SDA,
        .scl_io_num = OLED_SCL,
        .clk_source = I2C_CLK_SRC_DEFAULT,
        .glitch_ignore_cnt = 7,
        .intr_priority = 0,
        .trans_queue_depth = 0,
        .flags = {.enable_internal_pullup = true, .allow_pd = false}
    };

    i2c_master_bus_handle_t bus_handle;
    ESP_ERROR_CHECK(i2c_new_master_bus(&bus_cfg, &bus_handle));

    while (1) {
        ESP_LOGI("SCANNER", "Starting I2C scan...");

        uint8_t found_addresses[128] = {0};  // To store found devices
        int devices_found = 0;

        // Optional: Print classic grid header
        printf("     0  1  2  3  4  5  6  7  8  9  a  b  c  d  e  f\n");

        for (int addr = 0x00; addr <= 0x7F; addr++) {
            if (addr % 16 == 0) {
                printf("%02x: ", addr);
            }
            // Skip general call (0x00) and reserved addresses
            esp_err_t ret = i2c_master_probe(bus_handle, addr, 100);

            if (ret == ESP_OK) {
                printf("%02x ", addr);
                if (addr >= 0x08 && addr <= 0x77) {  // Find only count valid 7-bit addresses
                    found_addresses[devices_found++] = addr;
                }
            } else if (ret == ESP_ERR_NOT_FOUND) {
                printf("-- ");
            } else {
                printf("%d", ret);
                printf("UU ");  // Timeout or other error
            }

            if ((addr + 1) % 16 == 0) {
                printf("\n");
            }
        }
        // Print summary
        printf("\nScan complete: %d device(s) found.\n", devices_found);
        for (int i = 0; i < devices_found; i++) {
            printf("%d. Device 0x%02x address\n", i + 1, found_addresses[i]);
        }
        if (devices_found == 0) {
            printf("\n");  // Extra newline for readability when none found
        }
        // Repeats scan every 10 seconds (optional)
        vTaskDelay(pdMS_TO_TICKS(10000));
    }
}

extern "C" void app_main(void)
{
    vTaskDelay(pdMS_TO_TICKS(2000));

    //i2c_scanner_task();
    
    rc5_init(GPIO_NUM_4, GPIO_NUM_NC);

    gpio_config_t buttons[6] = {};
    buttons[0].pin_bit_mask = (1ULL << BUTTON_LEFT);
    buttons[1].pin_bit_mask = (1ULL << BUTTON_CENTER);
    buttons[2].pin_bit_mask = (1ULL << BUTTON_RIGHT);
    buttons[3].pin_bit_mask = (1ULL << SLIDER_UP);
    buttons[4].pin_bit_mask = (1ULL << SLIDER_DOWN);
    buttons[5].pin_bit_mask = (1ULL << SLIDER_PRESS);

    dev_cfg.flip_enabled = true;

    i2c_master_bus_config_t bus_config = {
        .i2c_port = I2C_NUM_0,
        .sda_io_num = OLED_SDA,
        .scl_io_num = OLED_SCL,
        .clk_source = I2C_CLK_SRC_DEFAULT,
        .glitch_ignore_cnt = 7,
        .intr_priority = 0,
        .trans_queue_depth = 0,
        .flags = {.enable_internal_pullup = true,.allow_pd = false},
    };
    ESP_ERROR_CHECK(i2c_new_master_bus(&bus_config, &busHandle));

    i2c_device_config_t i2cDev;

    ssd1306_init(busHandle, &dev_cfg, &dev_hdl);
    if (dev_hdl == NULL)
    {
        ESP_LOGE("MANDO", "ssd1306 handle init failed");
        assert(dev_hdl);
    }

    for (uint8_t i = 0; i < 6; i++)
    {
        buttons[i].mode = GPIO_MODE_INPUT;
        buttons[i].pull_down_en = GPIO_PULLDOWN_DISABLE;
        buttons[i].pull_up_en = GPIO_PULLUP_ENABLE;
        gpio_config(&buttons[i]);
    }

    ssd1306_clear_display(dev_hdl, false);
    menu_init(&dev_hdl);
    MenuInput menuInput = MENU_NONE;
    while (1)
    {
        if (gpio_get_level(BUTTON_LEFT) == 0)
        {
            printf("Sending START cmd\r\n");
            rc5_send(ADDR_STARTSTOP, 0x1B);
        }
        else if (gpio_get_level(BUTTON_RIGHT) == 0)
        {
            printf("Sending STOP cmd\r\n");
            rc5_send(ADDR_STARTSTOP, 0x1A);
        }

        menuInput = MENU_NONE;
        if (gpio_get_level(SLIDER_UP) == 0)
        {
            printf("Slider up!");
            menuInput = MENU_UP;
        }
        else if (gpio_get_level(SLIDER_DOWN) == 0)
        {
            printf("Slider down!");
            menuInput = MENU_DOWN;
        }
        else if (gpio_get_level(SLIDER_PRESS) == 0)
        {
            printf("Slider pressed!");
            menuInput = MENU_ENTER;
        }
        else if (gpio_get_level(BUTTON_CENTER) == 0)
        {
            menuInput = MENU_EXIT;
        }
        menu_loop(menuInput);
        vTaskDelay(pdMS_TO_TICKS(100));
    }
}

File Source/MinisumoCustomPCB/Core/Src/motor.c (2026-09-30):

#include "motor.h"
#include <stdio.h>
#include <string.h>
#include "stm32h5xx_hal.h"
#include "stm32h5xx_hal_gpio.h"
#include "stm32h5xx_hal_tim_ex.h"

void motor_init(Motor* dev)
{
    dev->reloadValue = __HAL_TIM_GET_AUTORELOAD(dev->init.timer);
}

void motor_setDuty(Motor* dev, MotorDirection dir, uint32_t duty)
{
    dev->currentSpeed          = duty;
    uint32_t      localDutyFwd = duty;
    uint32_t      localDutyBck = duty;
    uint32_t      localDuty;
    GPIO_PinState pinStateFwd;
    GPIO_PinState pinStateBck;

    if (dev->init.isReversed == 1) {
        pinStateFwd  = GPIO_PIN_RESET;
        pinStateBck  = GPIO_PIN_SET;
        localDutyFwd = duty;
        localDutyBck = 100 - duty;
    }
    else {
        pinStateFwd  = GPIO_PIN_SET;
        pinStateBck  = GPIO_PIN_RESET;
        localDutyFwd = 100 - duty;
        localDutyBck = duty;
    }

    if (dir == MOTOR_DIRECTION_FWD) {
        // If RESET/SET is swapped between directions
        // Move the localDuty adjustment
        localDuty = localDutyFwd;
        HAL_GPIO_WritePin(dev->init.directionPort, dev->init.directionPin, pinStateFwd);
    }
    else {
        localDuty = localDutyBck;
        HAL_GPIO_WritePin(dev->init.directionPort, dev->init.directionPin, pinStateBck);
    }

    if (localDuty <= MOTOR_DUTY_MAX_VALUE) {
        uint32_t calculatedPwmValue = dev->reloadValue / 100.0f * localDuty;
        __HAL_TIM_SET_COMPARE(dev->init.timer, dev->init.timerChannel, calculatedPwmValue);
    }
}

void motor_setTarget(Motor* dev, MotorDirection dir, uint32_t dutyTarget)
{
    dev->forcedMove  = 0;
    dev->targetSpeed = dutyTarget;
    if (dir != dev->targetDirection) {
        dev->currentSpeed = 0;
    }
    dev->targetDirection = dir;
    dev->lastMs          = HAL_GetTick();
    dev->startMs         = HAL_GetTick();
    dev->startSpeed      = dev->currentSpeed;

    return;
}

void motor_setForced(Motor* dev, MotorDirection dir, uint32_t dutyTarget)
{
    dev->forcedMove = 1;
    motor_setDuty(dev, dir, dutyTarget);
}

extern UART_HandleTypeDef huart5;
static uint8_t            uartBuf[200];

void motor_update(Motor* dev)
{
    // On forced move, dont use interpolation.
    if (dev->forcedMove == 1) {
        return;
    }
    uint32_t currentMs = HAL_GetTick();
    uint32_t deltaTms  = currentMs - dev->startMs;
    if (dev->currentSpeed == dev->targetSpeed) {
        return;  // Do nothing, motor already at desired speed.
    }
    uint32_t rate     = dev->maxRate;
    dev->currentSpeed = rate * deltaTms / 100 + dev->startSpeed;
    if (dev->currentSpeed >= dev->targetSpeed) {
        dev->currentSpeed = dev->targetSpeed;
    }
    /*else {
        snprintf((char*)uartBuf, 150, "$M:%lu,%lu;%lu;\r\n", currentMs, dev->startMs, dev->currentSpeed);
        HAL_UART_Transmit(&huart5, uartBuf, strlen((char*)uartBuf), 1000);
    }*/
    motor_setDuty(dev, dev->targetDirection, dev->currentSpeed);

    dev->lastMs = currentMs;

    return;
}

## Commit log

2026-09-25 PCB finished v1.0
    [EdgeCuts_PCB.dxf, MinisumoV2.kicad_pcb, MinisumoV2.kicad_sch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]
2026-09-25 HW: Minisumo PCB v1
    [MinisumoV2.kicad_pcb, MinisumoV2.kicad_sch, motors.kicad_sch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]
2026-09-25 Update PCB
    [MinisumoV2.kicad_pcb, MinisumoV2.kicad_sch]
2026-09-25 Update style
    [EdgeCuts_PCB.dxf]
2026-09-25 Fixed line sensor tracking
    [main.c, minisumo.c, motor.c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]
2026-09-25 Update de la doc
2026-09-28 Add 3D images
    [FullMango-BaseTRas.stl, FullMango-Frontal.stl, FullMango-Frontal_2.stl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]
2026-09-30 Add line sensor calibration

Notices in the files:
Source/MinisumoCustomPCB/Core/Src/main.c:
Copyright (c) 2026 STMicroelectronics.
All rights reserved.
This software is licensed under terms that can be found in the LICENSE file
